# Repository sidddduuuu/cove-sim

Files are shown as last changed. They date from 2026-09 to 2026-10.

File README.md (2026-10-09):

# Cove

Cove is a concept for a wave-powered offshore station that could recharge autonomous underwater vehicles (AUVs) and support repeated inspection missions. This repository contains **screening simulations, concept CAD, and a prototype plan**. It does not yet contain measured full-scale power output or autonomous AUV docking results.

- [Architecture, assumptions, and scaling](ARCHITECTURE_AND_SCALING.md)
- [Business analysis and customer questions](BUSINESS_ANALYSIS.md)
- [Two-week physical MVP plan](HOW_TO_BUILD_THE_MVP.md)
- [Good Bull pitch plan and display model](pitch/GOOD_BULL_2026.md)
- [Generated simulation results](RESULTS.txt)

The current Cove-S concept uses relative motion between a surface hull and submerged reaction body to drive a generator. The printed internal-mass prop in the pitch folder illustrates an earlier idea and is not a working generator or a model of the current architecture.

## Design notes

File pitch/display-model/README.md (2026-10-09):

# Cove pitch display model

This is a **nonfunctional, early internal-mass concept prop** for explaining wave-relative motion. The current Cove-S simulation and CAD instead depict a surface body and submerged reaction body with a power takeoff between them. Do not present this print as a scale model of that architecture or as evidence of electrical generation, watertightness, or autonomous AUV docking.

## Files and printing

- `Cove_shell_section_print_twice.stl`: print **two**; each section is 110 mm across and 85 mm tall, with a front cutaway.
- `Cove_end_cap_print_twice.stl`: print **two**; each cap is 110 mm across and 5 mm thick, with a 6.6 mm center hole.
- `Cove_pitch_model_preview.png`: assembly concept illustration, not a validated engineering drawing.

Suggested first slicer settings: PLA, 0.24–0.28 mm layers, three walls, 10–15% infill, no supports. Lay caps flat and print shell sections upright. Check the slicer preview and fit to your own printer before committing to a long print.

## Assemble

1. Glue the two shell sections end to end, aligning the openings. Glue on the bottom cap.
2. Place a smooth 6 mm rod or dowel about 180 mm long through the cap centers, fixed to the bottom cap.
3. Add a compression spring, a visible stack of M6 fender washers, and a second spring. Choose springs with an inside diameter over 6 mm. Check for roughly 20–40 mm of smooth travel.
4. Add the upper cap after confirming that the washer stack moves freely when the shell is moved vertically.
5. Make a visual AUV and cradle from a marker body, printed shape, pipe section, or foamboard. Mount the cradle below the shell on a rigid stand. It is a **dock mockup**, not a functioning charger.

Photograph the complete display, the cutaway, and a person holding it for scale. A short motion video can be captioned: **“Inertial-motion illustration; electrical output not tested.”**

If printing slips, a clear 100–120 mm plastic container, cardboard caps, and the same rod/washer/spring arrangement can serve as a fallback. The motion and honest labeling matter more than the finish.

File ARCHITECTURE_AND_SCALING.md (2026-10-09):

# Cove architecture and scaling: MVP → Cove S → Cove M → Cove L

This is the technical entry point for a new reader. See also [Business analysis](BUSINESS_ANALYSIS.md), [How to build the MVP](HOW_TO_BUILD_THE_MVP.md), and the [Good Bull pitch plan](pitch/GOOD_BULL_2026.md).

## Read this first

**Cove is an ocean-robot service-platform concept.** Its first proposed product, **Cove S**, is a mobile, wave-powered station that stores energy and recharges small autonomous underwater vehicles (AUVs) at a submerged dock. Its wave-driven propulsion is intended to reposition the station between service areas. The intended small-AUV battery class is roughly **1.5–5 kWh**.

The repository contains energy-balanced *screening* simulations, a draft detailed dynamics dashboard, concept CAD, and an at-home MVP build plan. None of these proves that a full-scale station can harvest the assumed power, survive offshore conditions, propel itself at the assumed speed, or dock an AUV unattended. Treat numerical outputs as conditional on assumptions until hardware and site-specific wave data validate them.

**Design-status convention used below:** *observed* = an identified measurement; *derived* = an equation or calculation from stated inputs; *assumed* = an unvalidated model parameter; *target* = desired future performance. Do not turn a target into a performance claim.

## Product architecture

```text
                  SURFACE PLATFORM (~8 m Cove S concept)
        navigation + communications + control + small auxiliary battery
                       wave-excited floats / hull
                                │
             compliant or telescoping connection with PTO
             relative heave → generator → power electronics
                                │ power/data umbilical and load path
                                │ mean depth target: 15–30 m
                                ▼
                   SUBMERGED REACTION BODY
            heave reaction + wave-propulsion hinged foils
             main battery pods + maneuvering thruster
                                │
                    funnel/latch/charging dock
                                ▼
                         visiting AUV
```

The surface body and submerged reaction body move differently in waves. Their **relative heave** must pass through a power-takeoff (PTO) mechanism to generate electricity. A rigid fixed-length beam that prevents relative axial movement cannot simultaneously provide substantial power from this heave-PTO path. The connection architecture must allow travel, carry structural loads, protect the umbilical, and handle end stops and overloads. Taut fixed-length tethers in parallel with the PTO would bypass its travel; a physically coherent safety/load path still needs engineering.

The submerged body is intended to react against wave motion, carry the dock in lower-motion water, and support hinged foils that turn part of the wave-induced motion into forward thrust. An electric thruster is reserved for maneuvering and low-wave contingencies. The **latest packaging concept** places the main battery in submerged pressure pods and only a small auxiliary battery on the surface hull. Some older model text and calculations still assume a surface battery; mass, buoyancy, cable losses, and power routing have not been reconciled. Neither battery should ride on the moving PTO member.

The dock is a vehicle-specific system, not just a funnel: an operational version needs navigation/acoustic or other homing, capture, latch, charging interface, communication/data offload, safe abort/release, and a fault-handling procedure. The MVP deliberately tests only guided passive capture, not autonomous docking or wet charging.

## Energy and mission model

The reduced-order Cove S model lives in `cove-s/cove-s-model.mjs`. It estimates whether an **assumed** wave-power capture and wave-propulsion capability could support station travel, hotel loads, battery reserve, and scheduled AUV charging.

Deep-water wave flux per metre of crest is screened as:

```text
J = ρ g² H² T / (64π)
```

where `H` is significant wave height and `T` is energy period. Electrical output is bounded by generator rating and calculated from wave flux × effective capture width × period response × PTO efficiency × the share remaining after propulsion allocation. The battery ledger integrates:

```text
ΔE = (Pwave − Photel − Pthruster − Pdock) × Δt
```

A charge session starts only if the station battery can finish while protecting its reserve. These equations are useful for consistency and sensitivities, but they do **not** establish a real capture width or propulsion map.

| Cove S screening input | Current default | Evidence status |
|---|---:|---|
| AUV pack / arrival | 3 kWh / 20% charge | Scenario assumption |
| Visits | 1 per day | Scenario assumption |
| Dock | 1.5 kW at 85% efficiency | Design assumption |
| Main battery | 60 kWh, 20% protected reserve | Design assumption; packaging unverified |
| Hotel load | 60 W | Design assumption |
| Generator ceiling | 2 kW | Rated-output target, **not average output** |
| Effective capture width / PTO efficiency | 0.35 m / 68% | Unmeasured assumptions |
| Energy allocated to wave propulsion | 18% | Unmeasured assumption |
| Maximum wave-driven speed | 1.5 knots | Unmeasured target |
| Service window | 6 hours per day | Scenario assumption |

At these defaults, one daily visit needs about **2.82 kWh from the station** to deliver 2.4 kWh to the AUV. With 60 W hotel load, the station needs at least **~178 W average generation** before propulsion and other losses. The 2 kW ceiling says nothing about whether that average is achieved across calm periods or at a customer's site. The model's four deterministic scenarios—design, variable, calm, storm—are screening histories, not annual site records.

### Detailed dashboard status

`cove-s/detailed/physics.mjs` and the four generated views (`whole.html`, `power.html`, `underwater.html`, `surface.html`) form a **draft** two-body heave/load simulation. It uses 2024 NOAA NDBC station 46005 observations stored in `cove-s/detailed/data/observations.json`; the data preparation keeps rows with simultaneous valid wave-height, dominant-period, and wind values. Preset sea states select real observation rows, while some stress cases are synthetic. Current is assumed, not observed. The model uses assumed hydrodynamic coefficients—not measured response functions or a WEC-Sim/BEM solution.

Its current default case warns that estimated travel exceeds an **assumed ±1.5 m PTO limit**; a **40 kN dynamic-force screening threshold** is also a model warning, not a certified structural rating. Do not hide these warnings or interpret model power outside the assumed envelope as deliverable. The detailed dashboard is not integrated into the root build/navigation; its model explanation is consolidated here.

The most important unfinished engineering tasks are: choose and model a buildable connection/load path; establish static preload and buoyancy equilibrium; replace guessed heave and damping coefficients; couple drag and surge to actual motion; reconcile battery pods, masses, and power routing; model stroke stops and storm survival beyond linear extrapolation; use sufficiently long and varied sea records; and carry uncertainty/validity metadata through the UI. A rigid-lock comparison should tend toward zero relative heave and zero heave-PTO output.

## The physical MVP and the scale-up path

These are **development stages**, not four finalized product specifications. Only Cove S has a concept envelope. Cove M and L should be sized *after* customer missions and measured S performance, not by multiplying CAD dimensions.

| Stage | Purpose | Hardware scope | Evidence needed before advancing |
|---|---|---|---|
| **Home MVP** | Show motion-to-electric conversion and guided dock geometry in 14 days | 0.4–0.6 m float, adjustable submerged plate, small line-driven generator, dry-side resistor/logger, 3D-printed funnel and passive vehicle | Repeated measured watts/Wh above baseline, logged stroke, retrievable buoyant rig, and reported guided-capture rate. See [build guide](HOW_TO_BUILD_THE_MVP.md). |
| **Cove S prototype** | Serve one specified small powered AUV at a chosen coastal/offshore test site | Engineered two-body WEC, protected storage, vehicle-specific submerged dock, navigation/control, supervised operations | Measured net wave-to-battery power matrix, repeated real-vehicle docking/charging, survival and maintenance evidence, site-specific energy ledger, permitting path. |
| **Cove S product** | Repeat the same job for multiple customers or sites | Design-for-manufacture station with documented interface, deployment/recovery procedure, remote operations and spares | Reliable unattended service interval, economics versus vessel/fixed dock, repeatable builds, support and liability model. |
| **Cove M (provisional)** | Support more frequent visits, larger AUV energy demand, or multiple compatible vehicles | Potentially larger converter, storage, and/or multi-vehicle dock; architecture selected from requirements | A named customer mission that S cannot meet; measured power/sea-state scaling; new structural, stability, and mooring/propulsion validation. |
| **Cove L (provisional)** | Support high-duty or multi-vehicle campaigns across a larger operating area | May require a different hull, WEC, dock, energy source mix, or service model—not merely enlarged S parts | Contract-level demand and economics plus full naval-architecture, safety, environmental, certification, and fleet-operations evidence. |

**Scale the validated service, not just the structure.** At each step, specify target vehicle(s), daily energy delivered, peak dock power, operating region and wave climate, station-keeping/mobility needs, recharge frequency, acceptable downtime, deployment/retrieval method, and permitted modification of the AUV. Size the WEC and buffer from the **worst credible operating window**, then check fatigue, stability, sealing, loads, biofouling, collision risk, and maintenance access. More visits and larger AUVs may require a different architecture altogether.

### Validation roadmap

1. **MVP evidence:** Measure motor/generator characteristics, output to a known load, PTO stroke, and guided dock capture. Log raw data and uncertainty. Do not claim AUV charging.
2. **Mechanism validation:** Bench/dynamometer-test PTO force–velocity behavior and losses. Wave-tank or controlled-water tests must measure both electrical power and relative motion across multiple wave states.
3. **Site and system model:** Replace effective capture width and speed assumptions with measured power and propulsion maps. Replay annual wave histories for an actual customer region. Balance generation, hotel load, propulsion, charging, and reserve.
4. **Vehicle-specific dock:** Choose one AUV interface. Test approach, capture, latch, power transfer, data transfer, abort, and release repeatedly under increasing motion/current.
5. **Offshore prototype:** Assess structural and fatigue loads, watertightness, corrosion, biofouling, stability, navigation safety, communications, environmental effects, and recovery. Obtain location-specific approvals before deployment.
6. **Commercial S, then M/L:** Validate total customer economics and reliability. Move up-market only when a real mission requires it and the smaller system's measured limits are known.

For the detailed dynamics model, essential invariant tests are: zero waves yield zero wave-generated power; zero relative velocity or zero PTO damping yields zero damper power; rigid lock suppresses the heave-PTO path; energy ledgers close; drag direction reverses with relative flow; and invalid stroke/load cases are flagged rather than ranked as feasible. Check source timestamps/units and missing values when preparing observational data.

## Repository map and how to run it

| Area | Contents | Status |
|---|---|---|
| `cove-s/cove-s-model.mjs` + `check-cove-s.mjs` | Deterministic mission/energy model and tests | Screening model; wired into root build |
| `cove-s/cove-s-simulation.template.html` → `cove-s-simulation.html` | Offline interactive mission page | Generated from source |
| `cove-s/detailed/` | `physics.mjs`, `ui.js`, four-view dashboard template/build/tests, NOAA preparation and observations | Draft; separate build |
| `cove-s/cad/` | CadQuery master, STEP/STL exports, renders | Packaging concept only |
| `strip/`, `sheet/`, `product/` | Earlier piezoelectric screening concepts | Retained as rejected/learning models |
| `tube/` | Earlier moving-magnet pipe screening concept | Retained as rejected/learning model |
| `node/` | Earlier sealed-pendulum node concept | Retained as a separate exploration |
| `build.mjs` / `run.mjs` | Offline page builder / parameter sweeps | Outputs generated HTML / `RESULTS.txt` |

Earlier piezoelectric options produced only microwatt-scale outputs in the model against a multi-kWh AUV pack. The upright moving-magnet pipe was mistuned to a typical wave period; the horizontal version trades tuning for friction and becomes very large for one charge/day. These are **model outcomes**, not physical measurements. The full parameter sweeps are generated in `RESULTS.txt`; the old concepts remain in code so assumptions can be inspected or retested.

Run from the repository root with Node 18+; the simulation scripts have no package-install step:

```bash
node strip/check.mjs
node sheet/check-sheet.mjs
node product/check-full.mjs
node tube/check-tube.mjs
node node/check-node.mjs
node cove-s/check-cove-s.mjs
node cove-s/detailed/check.mjs
node build.mjs
node cove-s/detailed/build.mjs
node run.mjs                  # regenerate RESULTS.txt
```

`strip/simulation.html` is hand-authored; the other root simulation pages are built from `*.template.html` plus model source. Do not hand-edit generated HTML. Change the corresponding model/template and rebuild. The model modules are deterministic and self-contained because builders inline them; Cove S's energy-residual and reserve checks should keep passing after changes. The detailed model uses SI internally; the mission model reports W, Wh, hours, metres, seconds, and knots.

To regenerate the observational dataset, use `python3 cove-s/detailed/prepare-data.py`. An optional browser smoke test is `python cove-s/detailed/browser-check.py` with Playwright and a suitable Chrome installation; it does not replace physics validation.

### Concept CAD and its limits

The editable CAD master is `cove-s/cad/cove_s_cad.py` (CadQuery, millimetres). It includes an approximately 8 m surface hull, PTO/generator housing, reaction body, foil pairs, maneuvering thruster, submerged dock, battery/power-electronics packaging, and a representative 2.7 m AUV. Exports under `cove-s/cad/exports/` include compact, operating-depth, and exploded STEP assemblies; component STEP/STL files are under `exports/parts/`, with previews in `renders/`.

```bash
uv run --with cadquery python cove-s/cad/cove_s_cad.py --export
```

Change the `Design` data class in the source to revise the envelope. The CAD is **not fabrication-ready**: it does not establish hull stability, PTO/tether loads, fatigue life, foil hydrodynamics, docking capture, pressure-housing integrity, mass/buoyancy balance, or maintenance access. A small FDM printer is most useful for MVP brackets, spool, guides, and a modular docking funnel—not pressure housings or primary offshore structural parts.

## Team ownership for the three-person MVP

- **Mechatronics lead:** PTO, float/plate structure, fasteners, spring/stops, electrical protection, and physical repairs.
- **Oceanography lead:** test-water setup, wave/sea-state characterization, ballast and depth choices, site representativeness, and interpretation of motion.
- **CS lead:** calibrated time-series logging, energy calculations (`P = V × I`, integrated Wh), test metadata, capture-trial records, plots, and reproducibility. Later this role expands to vehicle homing, docking control, charge-state logic, faults, telemetry, and fleet operations.

All three own safety and interpretation. The fastest convincing day-14 result is a **measured, repeatable experiment with honest limits**, not a claim that the eventual offshore station is already feasible.

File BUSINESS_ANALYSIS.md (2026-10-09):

# Cove business analysis

**Research snapshot:** September 29, 2026. **Geography:** United States and Europe. **Product in scope:** The mobile, wave-powered small-AUV charging station described in the [architecture and scaling guide](ARCHITECTURE_AND_SCALING.md).
**Evidence standard:** Public sources establish activities and stated capabilities, not purchasing intent. Vendor claims are identified as such. Inferences and unanswered questions are labeled.

## Executive assessment

Cove-S addresses a real operational constraint: battery-powered autonomous underwater vehicles (AUVs) may require a vessel to recover, recharge, and redeploy them. Offshore recharge could extend useful mission time and reduce some recovery effort. The [U.S. Department of Energy](https://www.energy.gov/sites/prod/files/2019/03/f61/73355.pdf) identifies AUV recharging as a potential marine-energy application, and [NOAA research](https://repository.library.noaa.gov/view/noaa/67166) identifies endurance and vessel-supported servicing as barriers to shipless survey.

The market is **not empty**. A [University of Washington field demonstration](https://www.nature.com/articles/s41598-026-55823-z) combined a wave-energy converter and submerged dock, reporting six successful docking attempts. Commercial vendors offer resident docks, and others are developing moving underwater docks and offshore charging platforms. Cove must therefore win on a particular customer mission, not on the novelty of wave-powered recharge alone.

**Working conclusion:** A focused paid pilot or integration business is plausible. Public evidence does not yet establish a large repeatable market for Cove-S. The major unknowns are customer economics, vehicle compatibility, actual net energy output, docking reliability, and the value of mobility.

## Customer job and product hypothesis

The customer would not buy wave energy for its own sake. The proposed job is to **keep a powered AUV collecting data or inspecting assets without bringing it back for every recharge**. Potential benefits include fewer recoveries, more continuous observations, and a charging location that can move between mission areas. These are hypotheses to test, not measured benefits.

The present [Cove-S architecture](ARCHITECTURE_AND_SCALING.md) proposes an approximately 8 m surface platform, wave-energy conversion, wave-driven propulsion, and a dock 15–30 m below the surface for AUVs with roughly 1.5–5 kWh battery packs. Its CAD and simulations are concept-stage screening tools, not proof of offshore performance.

### Energy-budget gate

The default [mission model](ARCHITECTURE_AND_SCALING.md) assumes one 3 kWh AUV visit per day, arrival at 20% state of charge, 85% dock efficiency, and a 60 W station hotel load:

| Quantity | Calculation | Result |
|---|---:|---:|
| Energy delivered to AUV | 3 kWh × 80% | 2.40 kWh/visit |
| Energy drawn from station | 2.40 kWh ÷ 85% | 2.82 kWh/day |
| Station hotel load | 60 W × 24 h | 1.44 kWh/day |
| **Minimum sustained generation** | (2.82 + 1.44) kWh ÷ 24 h | **~178 W average** |

That average excludes propulsion, communications peaks, storage losses, and calm-weather reserve recovery. The modeled **2 kW generator rating is a maximum, not evidence of 178 W sustained average generation**. Capture width, power-takeoff efficiency, and propulsion performance remain assumptions. For context, the published [UW TigerRAY demonstration](https://www.nature.com/articles/s41598-026-55823-z) was designed for 100 W in its target conditions; it is not an apples-to-apples performance comparison with Cove. Its testing illustrates the importance of measured wave-to-wire output and power-electronics losses.

The team should select a real customer vehicle and operating region before asserting a charge-per-day capability. Historical sea states can be screened with [NOAA NDBC archives](https://www.ndbc.noaa.gov/historical_data.shtml) in the United States and [Copernicus Marine wave reanalysis](https://data.marine.copernicus.eu/product/GLOBAL_MULTIYEAR_WAV_001_032/description?product_id=-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) for European regions.

## Customer segments

| Segment | Potential reason to care | Main qualification question | Priority |
|---|---|---|---|
| Powered-AUV research teams | Longer sampling campaigns and fewer vehicle recoveries | Does recharge solve an actual mission bottleneck, or are payload, data, and vessel logistics more limiting? | First interviews and pilots |
| Commercial survey and offshore-inspection operators | Vessel time and continuous inspection coverage have economic value | Can Cove beat an existing vessel, resident dock, or uncrewed surface vessel on total operating cost and reliability? | Early economic validation |
| AUV makers and dock integrators | Possible power-and-docking platform partnership | Will they support a reusable charging interface rather than a one-off custom integration? | Partnership interviews |
| Defense and government operators | Persistent, potentially relocatable underwater operations | What mission and sponsor can be discussed and tested openly? | Later, unless a direct sponsor exists |

These are **prospect categories, not validated buyers**. [WHOI](https://www.whoi.edu/what-we-do/explore/underwater-vehicles/auvs/remus/) develops and operates REMUS AUVs, the [UK National Oceanography Centre](https://www.noc.ac.uk/our-work/marine-technology) operates an underwater-robot fleet, and [Oceaneering](https://www.oceaneering.com/rov-services/rov-systems/freedom-autonomous-underwater-vehicle/) markets a resident-capable AUV. None of those facts establishes demand for Cove.

**Likely initial fit — inference:** a powered AUV carrying energy-intensive sensors or repeating short missions. Extremely low-power gliders may be a weaker first segment because existing models can operate for long periods. [Teledyne](https://www.teledynemarine.com/products/product-line/autonomous-underwater-glider) describes long-endurance Slocum gliders; [NOC](https://www.noc.ac.uk/news/european-research-institute-acquire-noc-autonomous-underwater-vehicles) describes multi-week to multi-month Autosub Long Range missions.

## Competitive and substitute landscape

| Alternative | Evidence | What Cove must demonstrate |
|---|---|---|
| Recover and recharge from a vessel | [NOAA](https://repository.library.noaa.gov/view/noaa/67166) identifies endurance, recovery, and servicing as obstacles to shipless survey. | Sufficient avoided recovery work or added mission output to justify Cove's full cost. |
| More onboard energy or long-endurance vehicles | [NOC](https://www.noc.ac.uk/news/european-research-institute-acquire-noc-autonomous-underwater-vehicles) and [Teledyne](https://www.teledynemarine.com/products/product-line/autonomous-underwater-glider) show long-endurance alternatives. | A mission that remains energy-limited despite these options. |
| Fixed or resident subsea docks | [Saab Sabertooth](https://www.saab.com/products/sabertooth) and [Oceaneering Liberty](https://www.oceaneering.com/rov-services/rov-systems/liberty-resident-system/) offer subsea residence and recharge; Liberty has a large onboard battery. | A meaningful benefit from local generation and independent relocation. |
| Wave-powered underwater-dock research | [UW TigerRAY](https://www.nature.com/articles/s41598-026-55823-z) has field results; [DOE-funded Oregon State work](https://stage.energy.gov/cmei/water/funding-selections-marine-energy-university-foundational-rd) pursues related integration. | A distinct customer outcome, stronger performance, or better deployment economics. |
| Moving docks and offshore charging platforms | [Unplugged](https://www.unplugged.no/projects/underwater-refuelling-in-motion) reports a USV-towed submerged dock with 500 W inductive charging. [Ocean Power Technologies](https://investors.oceanpowertechnologies.com/node/17091) has announced progress on offshore charging and docking. | Why Cove's power source, mobility, dock depth, interface, or operating model wins in a named mission. |

Vendor pages establish what suppliers **claim or are developing**; they are not independent proof that all advertised capabilities work in every sea state.

### Potential differentiation to test

> A relocatable, independently powered charging point for small powered AUVs where a fixed dock or support vessel is impractical.

This is a **positioning hypothesis**, not a verified customer requirement. It depends on all three conditions below:

1. The customer needs the charging point to move during a campaign or between nearby missions.
2. Cove has sufficient *net* energy after propulsion, hotel loads, docking losses, and low-wave periods.
3. A compatible AUV can dock and charge reliably without an uneconomic redesign.

If the customer can leave the dock fixed, mobility may add complexity without adding value.

## SWOT analysis

| Strengths | Weaknesses |
|---|---|
| Cove integrates local generation, relocation, and submerged docking in one concept. A small-AUV focus narrows the initial interface problem. | No measured full-scale output, docking success rate, mobility, survivability, or service interval. Current CAD and models are not validated product performance. [Architecture and scaling guide](ARCHITECTURE_AND_SCALING.md) |
| The proposed customer outcome—less recovery and more useful mission time—is testable. | Energy, navigation, docking, and unattended reliability must all work together. Vehicle-specific integration may make early sales custom projects. |

| Opportunities | Threats |
|---|---|
| AUV users seek less vessel-dependent operations; relevant operators exist in research and inspection. [NOAA](https://repository.library.noaa.gov/view/noaa/67166), [Oceaneering](https://www.oceaneering.com/rov-services/rov-systems/freedom-autonomous-underwater-vehicle/) | Established vendors and funded researchers are already pursuing subsea docks, wave recharge, and moving docks. [UW](https://www.nature.com/articles/s41598-026-55823-z), [Unplugged](https://www.unplugged.no/projects/underwater-refuelling-in-motion) |
| A vehicle-maker or operator partnership could provide a real interface and pilot mission. Historical wave datasets support site screening. [NOAA NDBC](https://www.ndbc.noaa.gov/historical_data.shtml), [Copernicus Marine](https://data.marine.copernicus.eu/product/GLOBAL_MULTIYEAR_WAV_001_032/description?product_id=-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) | Better batteries, low-power vehicles, and uncrewed surface-vessel support may be good-enough substitutes. Deployment approvals and liability may lengthen pilots. [Teledyne](https://www.teledynemarine.com/products/product-line/autonomous-underwater-glider), [Fugro](https://www.fugro.com/expertise/case-studies/ensuring-sustainable-offshore-wind-farm-maintenance-hollandse-kust-zuid-inspection), [U.S. agency overview](https://www.boem.gov/renewable-energy/agency-approval), [UK licensing](https://www.gov.uk/guidance/make-a-marine-licence-application) |

## Market size and economics

**No defensible numeric total addressable market was found.** A broad AUV-industry estimate would include many vehicles and buyers for whom Cove is irrelevant. The serviceable market should instead be counted from named fleets that meet all of these filters:

- A compatible powered AUV and repeated remote missions.
- A material endurance or recovery problem that recharge would solve.
- A viable wave climate and deployment location.
- A technically and commercially feasible dock interface.
- An identifiable buyer and procurement path.

Use a bottom-up model:

```text
Potential stations = qualifying operators × relevant missions/operator × stations/mission
Potential annual revenue = stations sold or deployed × price + service/integration revenue
```

For a customer, the break-even question is:

```text
avoided vessel/recovery cost + value of additional mission output
    > Cove purchase or rental + deployment/retrieval + integration
      + maintenance + insurance + operational risk
```

Reliable public figures for Cove-specific pricing, customer vessel-day costs, willingness to pay, and maintenance burden were **not found**. Those inputs require operator interviews and supplier quotes. **Inference:** early revenue is more likely to come from paid pilots and custom integration than standardized station sales; repeatability depends on a reusable vehicle interface and proven unattended operation.

## U.S. and European outreach map

These are **interview targets, not confirmed buyers**. The best initial contact is usually an AUV operations lead, fleet manager, or mission/program manager.

| Priority | Organization | Reason to contact | Main question |
|---|---|---|---|
| 1 | [WHOI Oceanographic Systems Lab, U.S.](https://www.whoi.edu/what-we-do/explore/underwater-vehicles/auvs/remus/) | Develops and operates REMUS AUVs. | Which powered-AUV missions are recovery-limited, and what interface could be piloted? |
| 1 | [NOAA Office of Coast Survey, U.S.](https://nauticalcharts.noaa.gov/learn/uncrewed-systems.html) | Uses AUVs for hydrographic survey. | Would recharge add survey time, or is another constraint dominant? |
| 1 | [National Oceanography Centre MARS, UK](https://www.noc.ac.uk/our-work/marine-technology) | Operates an advanced AUV fleet. | Which missions still need offshore recharge despite long-endurance vehicles? |
| 1 | [Fugro, Netherlands/UK operations](https://www.fugro.com/expertise/case-studies/ensuring-sustainable-offshore-wind-farm-maintenance-hollandse-kust-zuid-inspection) | Performs remote offshore inspection. | Could Cove beat its existing uncrewed-vessel approach on a specific job? |
| 2 | [MBARI LRAUV team, U.S.](https://www.mbari.org/team/lrauv/) | Extensive AUV and charging experience. | What worked or failed, and where is its [existing solar dock](https://www.mbari.org/news/mbari-research-expedition-provides-a-detailed-snapshot-of-life-in-monterey-bay/) insufficient? Treat as an expert interview, not a greenfield sale. |
| 2 | [ARDITI, Portugal](https://www.noc.ac.uk/news/european-research-institute-acquire-noc-autonomous-underwater-vehicles) | Acquiring two NOC AUVs for offshore science. | Is high-power payload operation constrained by recharge? |
| 2 | [GEOMAR, Germany](https://www.geomar.de/st/auv) | Operates research AUVs. | What are recovery frequency, sea-state limits, and vehicle-modification constraints? |
| 2 | [Ocean Infinity, UK](https://oceaninfinity.com/news/ocean-infinity-launches-needlefish-usv-in-kuwait/) | Operates uncrewed maritime systems. | Would an independent charging node fit its fleet architecture? |
| Expert/partner | [UW Applied Physics Laboratory, U.S.](https://www.nature.com/articles/s41598-026-55823-z) | Direct wave-converter/dock field experience. | What technical and operational lessons should Cove incorporate? |
| Expert/partner | [Unplugged, Norway](https://www.unplugged.no/projects/underwater-refuelling-in-motion) | Developing a closely related moving dock. | Are interface standards or partnership opportunities emerging? |

## Unknowns for customer discovery

Do **not** replace these with unsourced market estimates. Request evidence from recent missions, logs, budgets, quotes, and pilot requirements.

| Unknown | Question for the customer | Why it matters |
|---|---|---|
| Mission pain | In the last 12 months, how many missions ended or paused because of energy? | Establishes frequency and severity. |
| Recovery economics | What vessel, crew, and weather-window effort did a recent recharge/redeployment require? | Sets the value ceiling. |
| Vehicle fit | Which exact AUV, battery, charging protocol, geometry, and permitted modifications? | Determines integration feasibility. |
| Energy demand | How many kWh per visit, how often, and how quickly? | Sets generation, battery, and dock requirements. |
| Mobility | Does the dock need to move? How far and how frequently? | Tests Cove's central differentiator. |
| Reliability | What docking-success rate and unattended service interval would be acceptable? | Defines pilot success and risk. |
| Substitutes | Why not more batteries, a fixed dock, or an existing uncrewed surface platform? | Identifies true competition. |
| Buyer and timing | Who owns the budget, and what evidence is needed for a paid pilot? | Distinguishes interest from purchase intent. |
| Commercial model | Purchase, campaign rental, or service contract? At what budget level? | Enables pricing and market sizing. |
| Deployment | Who handles permits, marking, insurance, recovery, and maintenance? | Determines adoption time and total cost. |

For the first conversation, ask about the **last specific mission before presenting Cove**. A documented recovery event and its cost are stronger evidence than a positive reaction to a concept drawing.

## Proposed validation decision

After 15–20 interviews, proceed toward a customer-specific pilot only if the team has:

1. At least **two operators** with a named recurring mission where offshore recharge would measurably improve results.
2. At least **one vehicle/platform partner** willing to specify a real dock and charging interface.
3. A measured prototype energy budget plausibly sufficient for that mission across its site-specific sea-state history—not just a generator peak rating.

These are **proposed go/no-go criteria**, not sourced market statistics. The existence of an endurance problem is supported; demand for Cove-S's particular solution remains to be validated.

## Research limitations and update triggers

- Public product pages often describe vendor plans or self-reported capabilities, not independently verified deployments.
- An organization's AUV ownership is not proof of a current recharge need, budget, or purchasing authority.
- This report is a September 2026 snapshot. Recheck competitor status, permits, and target organizations before making an investment or deployment decision.
- Update this file with interview evidence, named vehicle specifications, supplier quotes, and measured prototype results. Keep observed facts separate from assumptions.

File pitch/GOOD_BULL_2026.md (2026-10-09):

# Cove at Good Bull Pitch — October 12, 2026

**Format:** 8-minute pitch, then 4 minutes of questions (team-provided timing).

**Purpose:** present a testable business and engineering plan, not a validated offshore product.

## The focus

Lead with one proposed customer job: **repeat inspection of offshore infrastructure, starting with a pipeline corridor**. The buyer would pay for timely inspection data. Cove's proposed wave-powered charging station is the means to keep a compatible AUV operating near that job with fewer recovery trips. A paid data/inspection service is the first business-model hypothesis; charging AUVs owned by other operators is a later hypothesis that requires a proven interface and enough spare energy.

This customer, job, and willingness to pay are **not yet validated**. Do not claim a signed customer, measured vessel savings, or a price without evidence. If interviews identify a stronger first use case, change the pitch accordingly.

## Eight-minute run of show

| Time | Slide / prop | Main point |
|---|---|---|
| 0:00–0:50 | Problem | Repeated AUV recovery and redeployment can interrupt offshore inspection work. Establish this as the customer problem to investigate. |
| 0:50–1:40 | First buyer and mission | Name the proposed pipeline-inspection operator, recurring mission, and value of more frequent data. Avoid a broad claim about all AUVs. |
| 1:40–3:00 | Cove system | Show a surface energy harvester, storage, submerged dock, and one compatible AUV. Describe the mission loop: inspect, dock, recharge, upload, relaunch. |
| 3:00–4:00 | Physical display | Show the scale mockup and explain exactly what it demonstrates. Refer to the [display-model guide](display-model/README.md). |
| 4:00–5:00 | Business model | First, sell a recurring inspection/data service with Cove-operated AUVs; later, consider third-party docking once charging compatibility and capacity are measured. |
| 5:00–6:20 | Evidence and unknowns | Distinguish existing screening calculations and CAD from measured generation, autonomous docking, and offshore reliability. State the next tests. |
| 6:20–7:20 | Milestones and ask | Explain how prize funds would support an instrumented power-takeoff test, guided docking test, and customer interviews. Use an actual budget when available. |
| 7:20–8:00 | Buffer and close | Repeat the intended customer outcome and the immediate validation milestone. |

## Numeric claim discipline

The current Cove-S model is a **screening scenario**. For its assumed 3 kWh AUV arriving at 20% charge, 85% dock efficiency, and 60 W station hotel load, one visit per day needs about **2.82 kWh/day from the station for charging** plus **1.44 kWh/day for hotel loads**: about **178 W sustained average generation** before propulsion and other losses. This is a *requirement derived from assumptions*, not measured Cove output. The model's 2 kW generator ceiling is a target/rating cap, not 2 kW continuous generation.

Do not promise hundreds of missions per day, universal AUV compatibility, or a specific reduction in vessel cost. Count a "mission" only after defining its duration, battery energy, and recharge need. Energy, dock throughput, and maintenance all constrain daily mission count.

## Four-minute Q&A preparation

| Question | Short answer |
|---|---|
| How much power have you generated? | Current numbers are assumption-based models. The next test will log voltage, current, load, motion, and watt-hours over repeatable runs. |
| Why would an operator pay? | The hypothesis is that more frequent inspection data and fewer recovery operations have value. Operator interviews and a mission-specific pilot must establish the economics. |
| Can any AUV dock? | No. The first pilot needs one chosen vehicle, charging protocol, homing method, and mechanical interface. |
| Why waves instead of solar or a larger battery? | Compare a site-specific power mix. Wave energy is a candidate; actual sea-state history and net energy measurements must justify it. |
| Is this working hardware? | The pitch prop is a display mockup. It demonstrates layout or relative motion only; it does not prove wave-to-wire power, autonomous docking, or offshore survival. |

## By pitch day

1. Freeze a seven-slide deck and label every number **measured**, **derived from assumptions**, or **target**.
2. Assemble and photograph the physical display. Use one wide view, one mechanism close-up, and one scale view with a person.
3. If any electrical test succeeds, report the raw load, measurement interval, watts, and watt-hours. If it does not, show the motion/layout only.
4. Rehearse to 7:20, leaving 40 seconds of margin, then practice the five Q&A answers above.

The existing Cove-S model and concept CAD are in [`cove-s/`](../cove-s/). The display-model package below is an **earlier internal-mass illustration** and does **not** implement the current two-body Cove-S power-takeoff architecture. If the deck shows the current architecture, use the repository's Cove-S CAD renders as the primary system visual and introduce this prop only as an early motion concept.

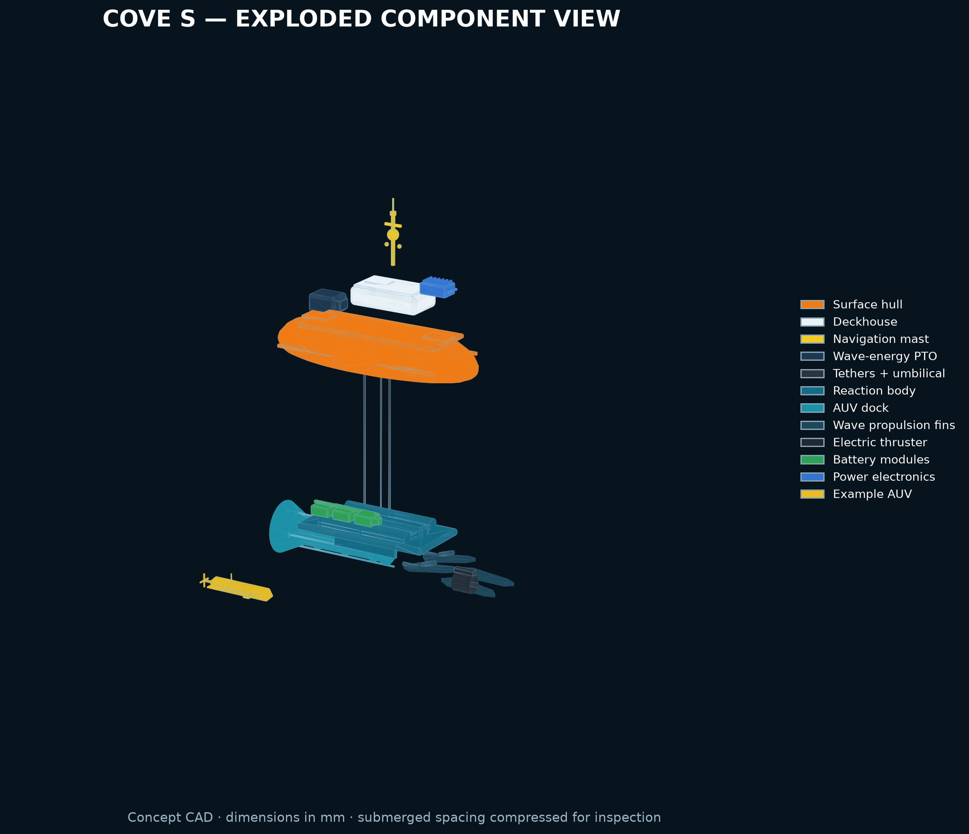
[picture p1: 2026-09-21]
cove-s/cad/renders/cove-s-exploded.png

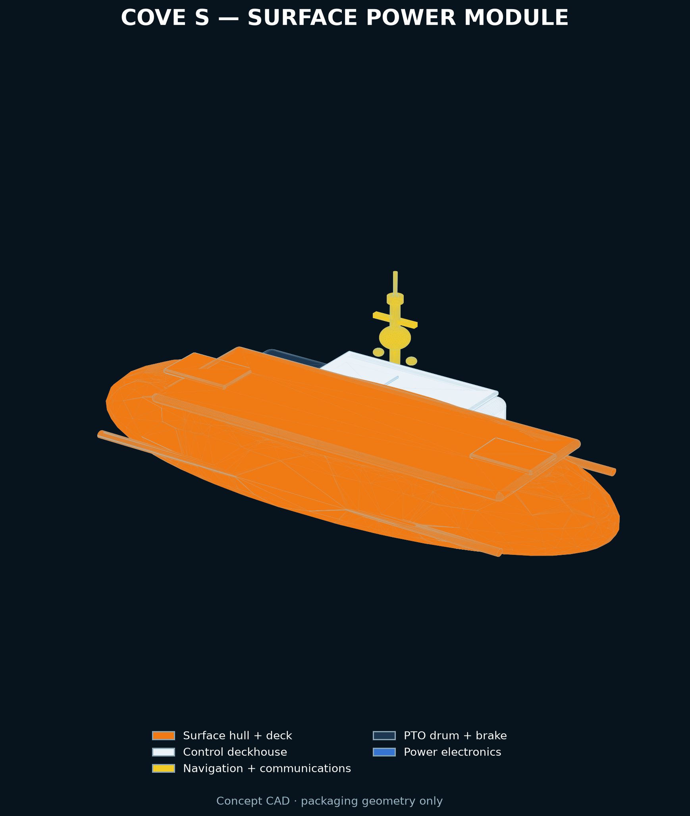
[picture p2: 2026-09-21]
cove-s/cad/renders/cove-s-surface-module.png

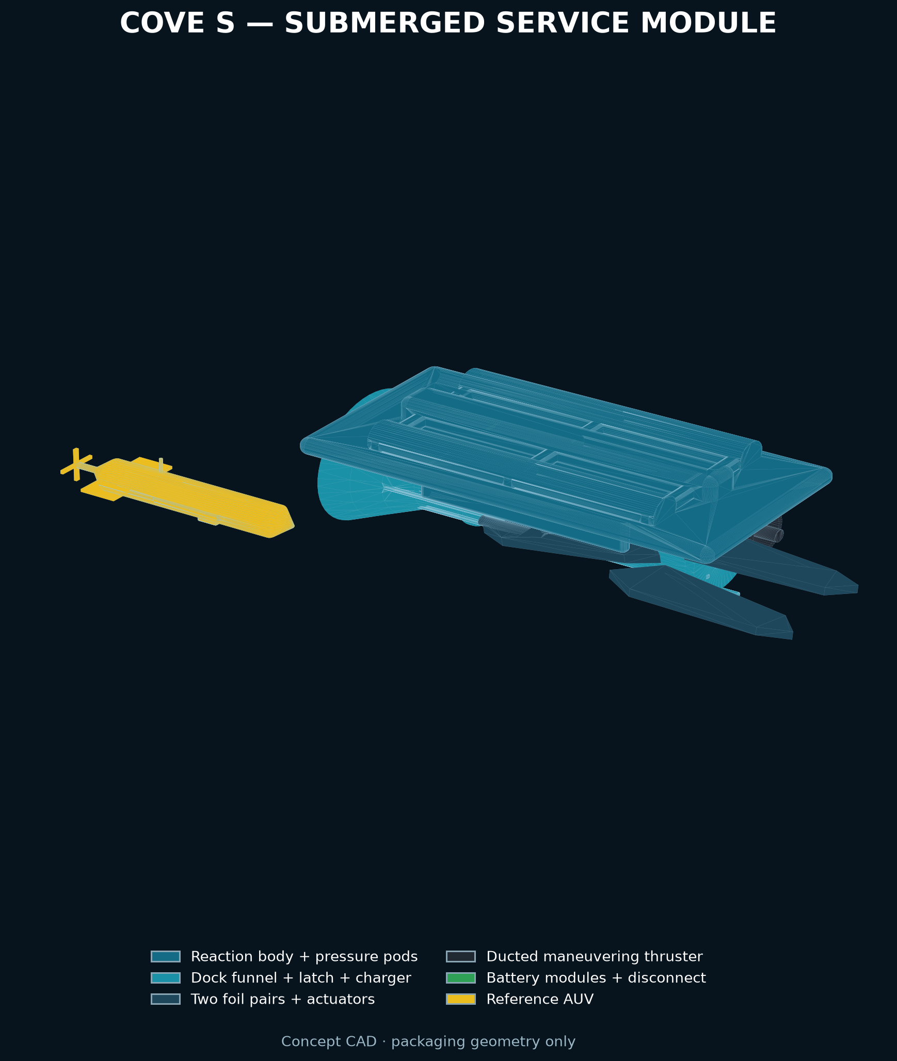
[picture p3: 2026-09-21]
cove-s/cad/renders/cove-s-submerged-module.png

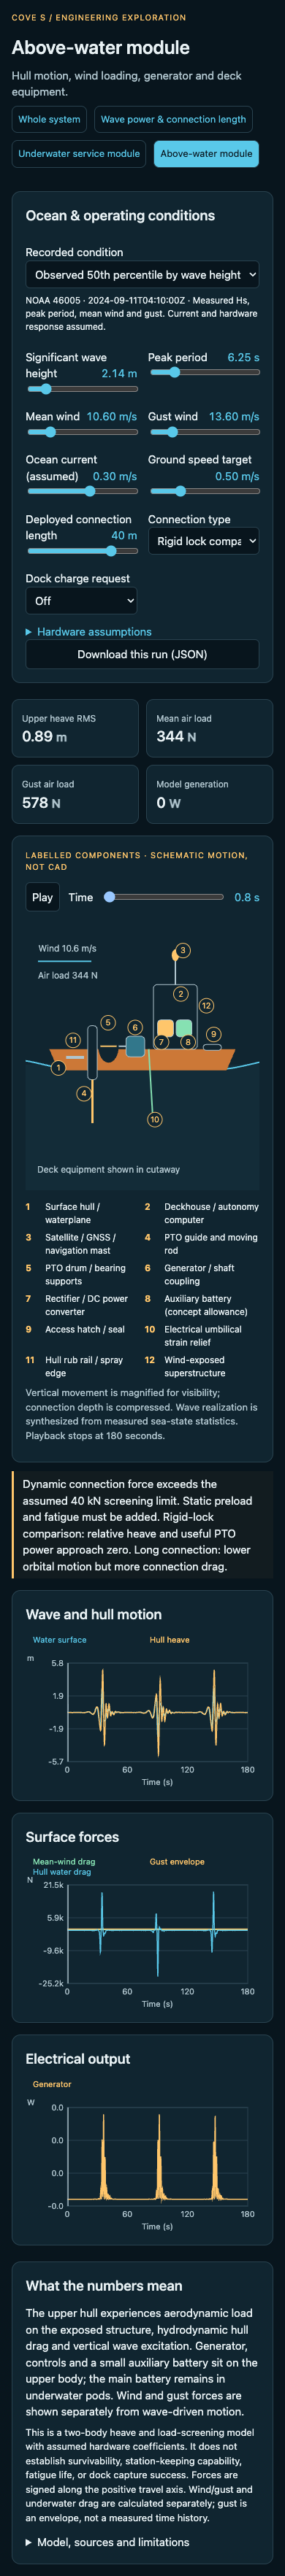
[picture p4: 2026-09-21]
cove-s/detailed/previews/surface-mobile.png

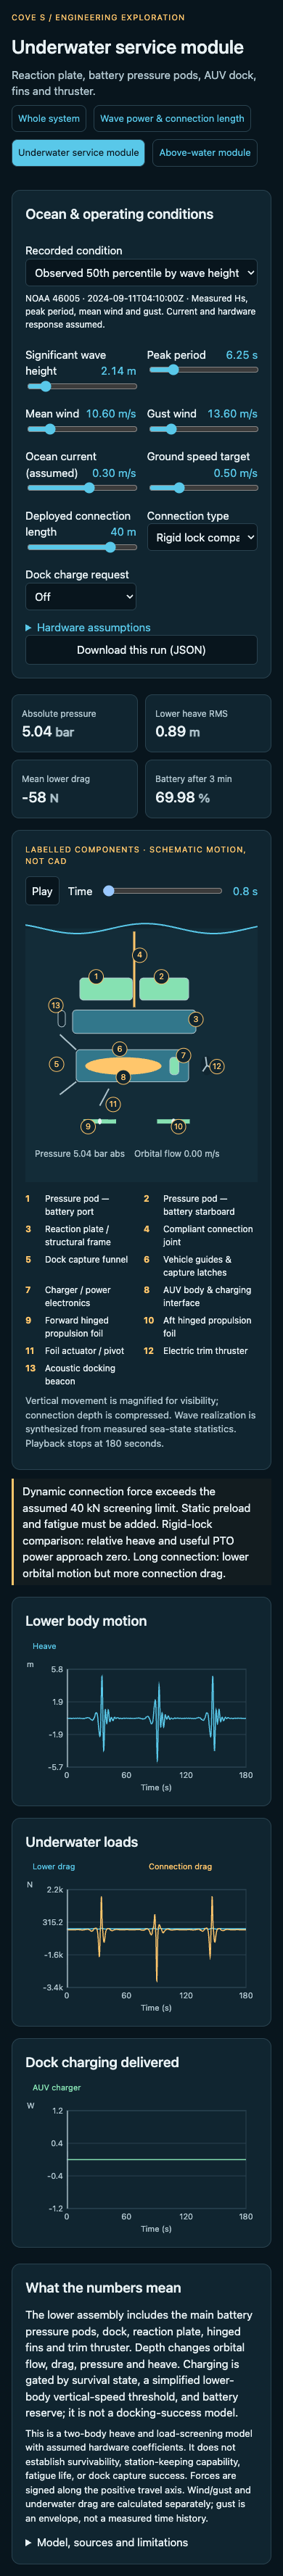
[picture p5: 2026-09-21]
cove-s/detailed/previews/underwater-mobile.png

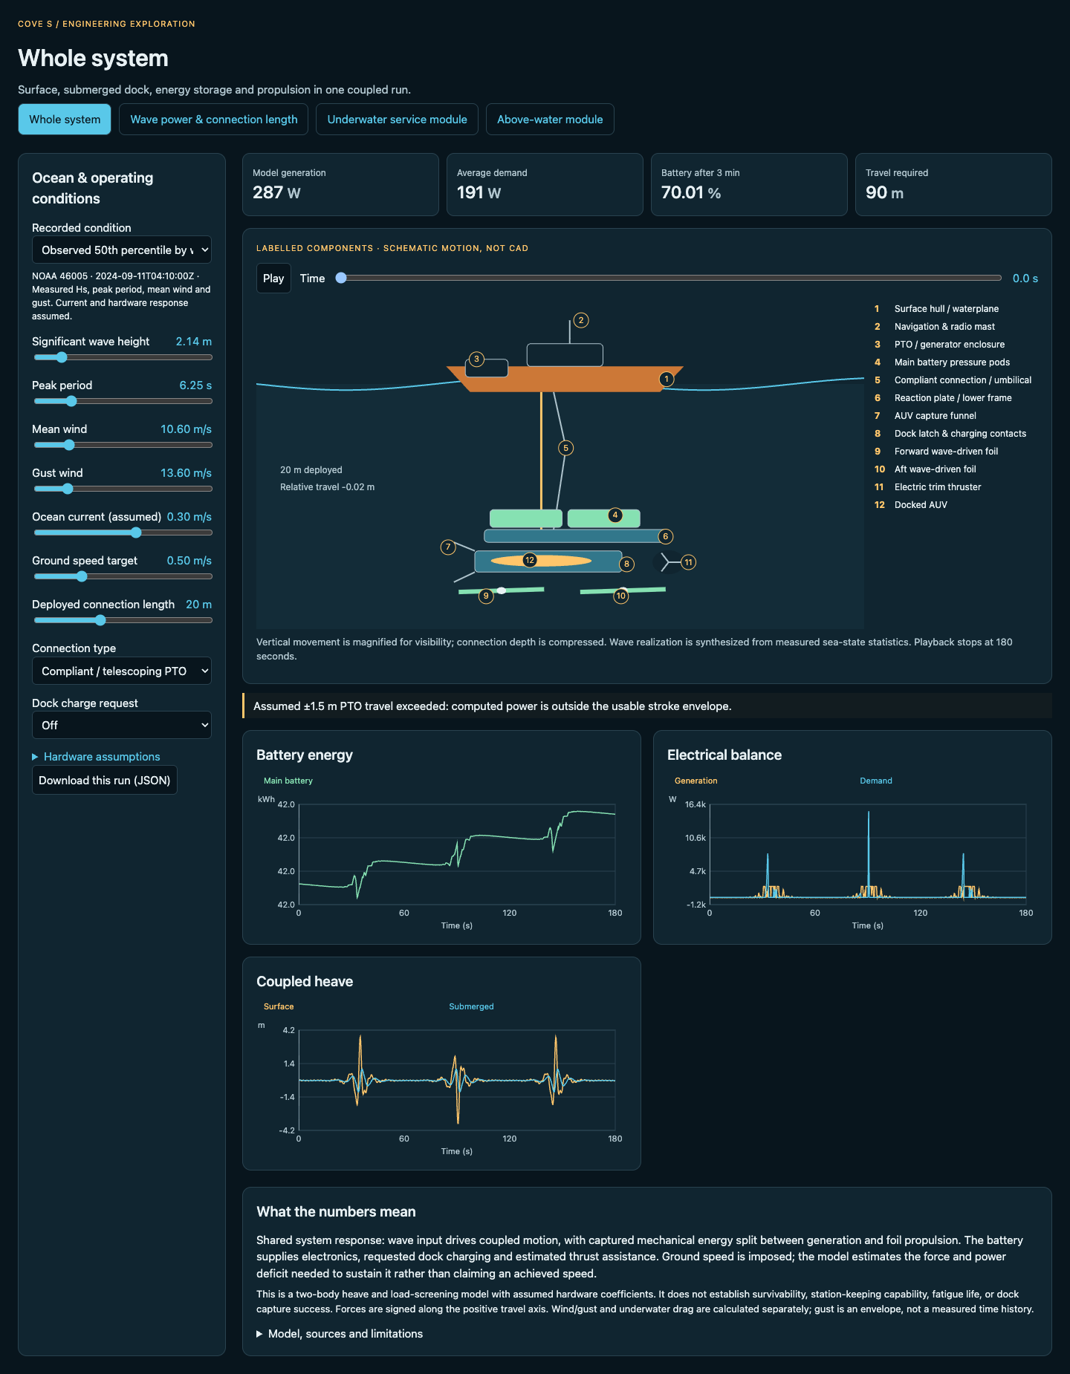
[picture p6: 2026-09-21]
cove-s/detailed/previews/whole.png

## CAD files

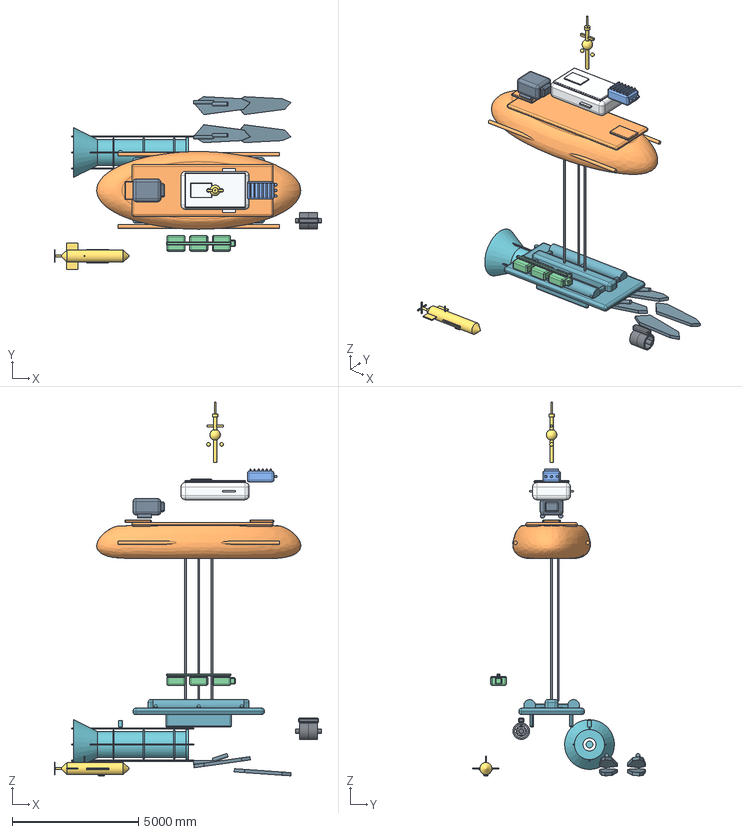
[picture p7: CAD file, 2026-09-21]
cove-s/cad/exports/cove-s-exploded-assembly.step
10587.5 x 6835.0 x 14805.0 mm
surface_hull
deckhouse
mast
pto
tethers
reaction_body
dock
foils
thruster
battery
electronics
auv

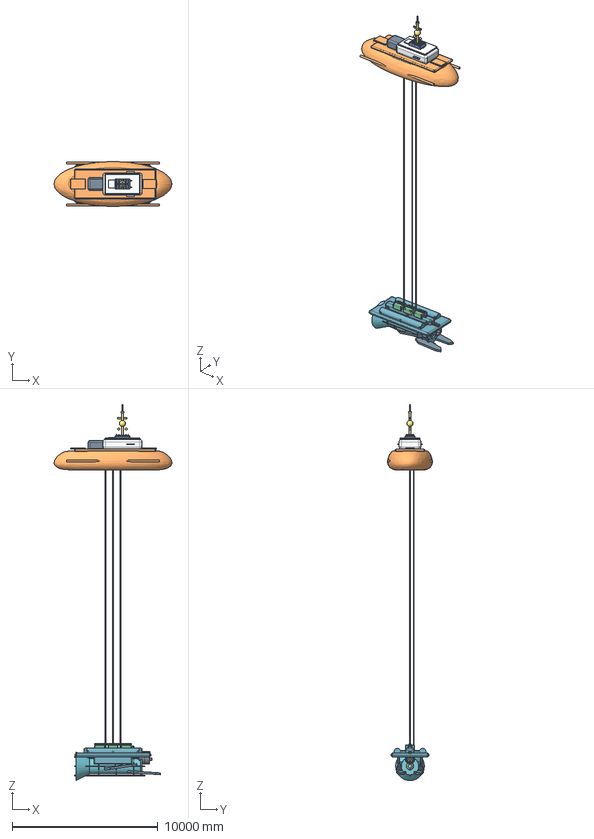
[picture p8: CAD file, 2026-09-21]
cove-s/cad/exports/cove-s-operating-depth-assembly.step
8083.7 x 3078.1 x 25793.1 mm
surface_hull
deckhouse
mast
pto
tethers
reaction_body
dock
foils
thruster
battery
electronics
auv

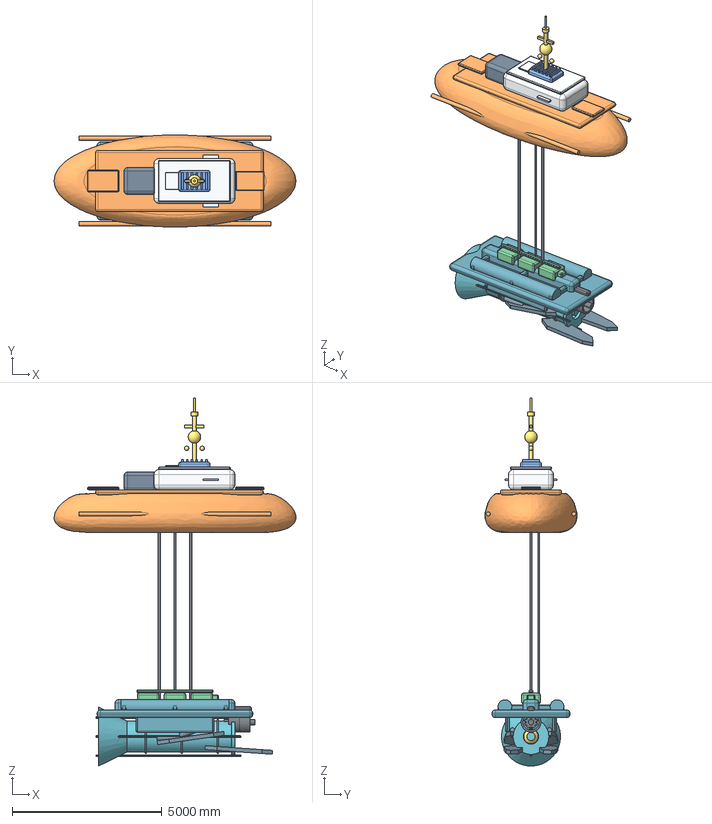
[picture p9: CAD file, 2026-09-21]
cove-s/cad/exports/cove-s-compact-assembly.step
8083.8 x 3078.1 x 12293.1 mm
surface_hull
deckhouse
mast
pto
tethers
reaction_body
dock
foils
thruster
battery
electronics
auv

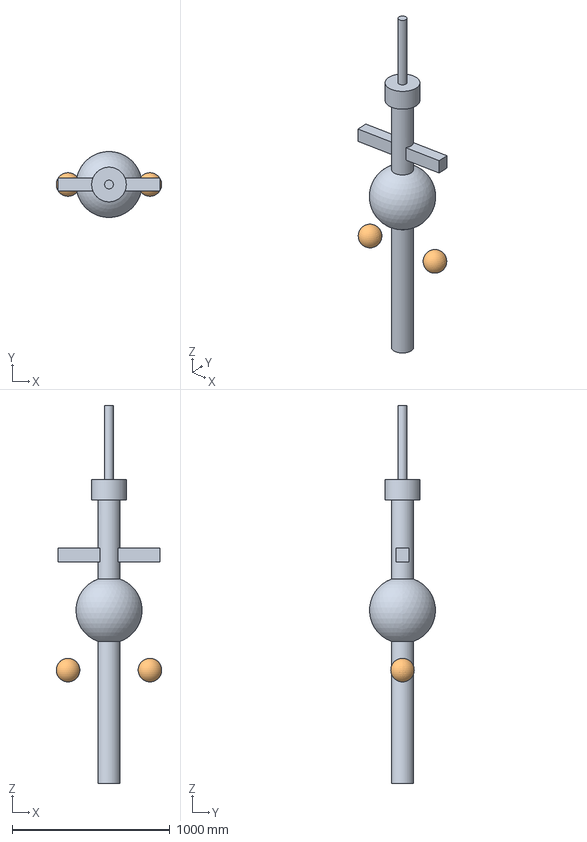
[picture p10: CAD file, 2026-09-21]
cove-s/cad/exports/parts/mast.step
669.7 x 418.6 x 2400.0 mm

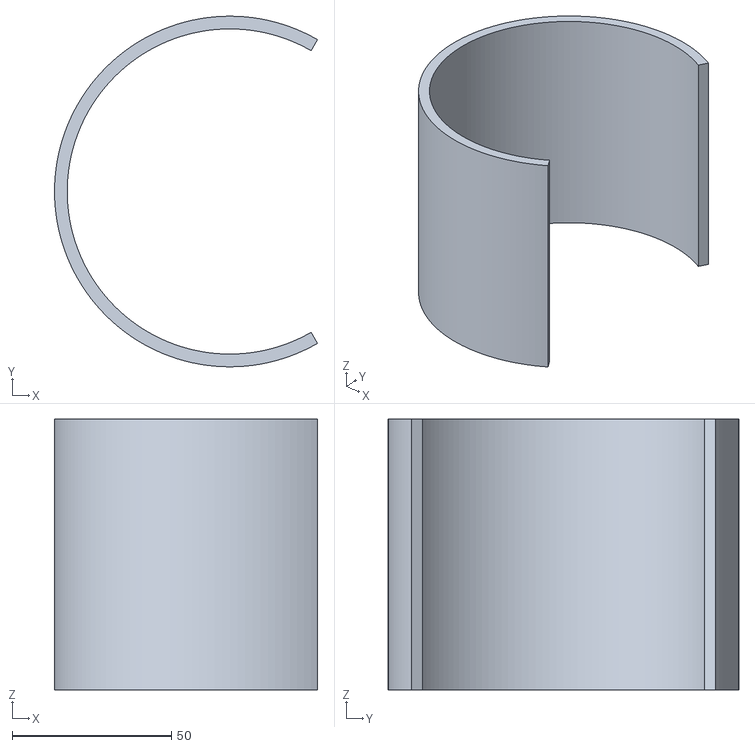
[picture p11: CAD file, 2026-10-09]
pitch/display-model/Cove_shell_section_print_twice.stl
82.5 x 110.0 x 85.0

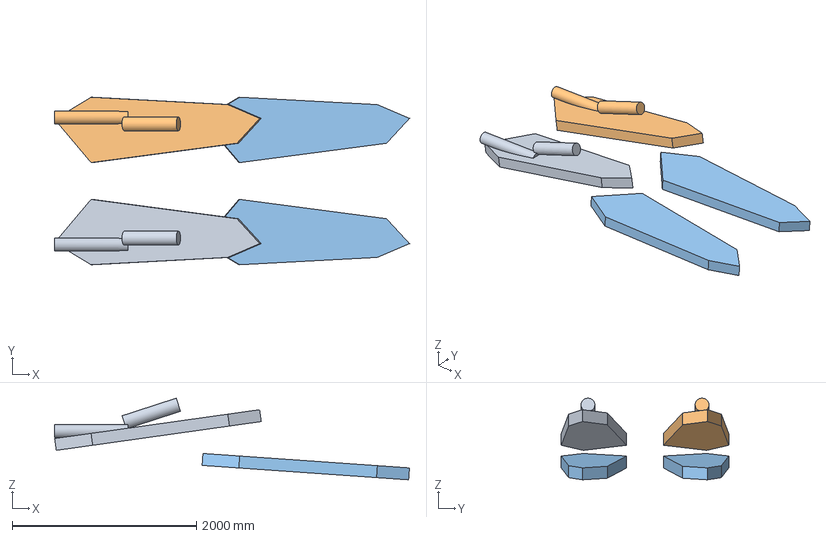
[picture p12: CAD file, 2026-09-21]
cove-s/cad/exports/parts/foils.step
3857.2 x 1820.0 x 887.6 mm

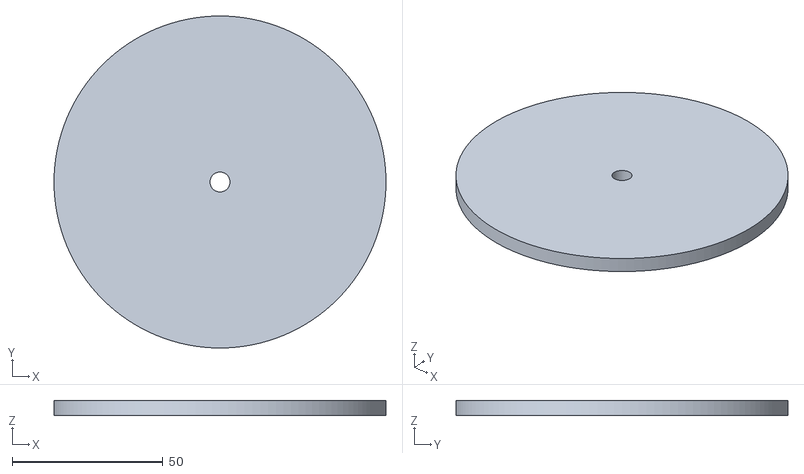
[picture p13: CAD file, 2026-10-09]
pitch/display-model/Cove_end_cap_print_twice.stl
110.0 x 110.0 x 5.00

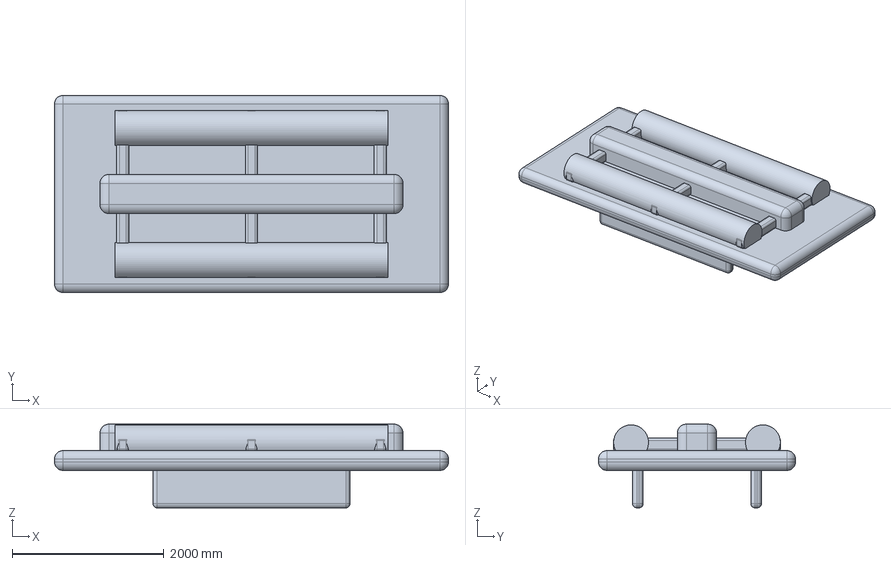
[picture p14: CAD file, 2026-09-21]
cove-s/cad/exports/parts/reaction_body.step
5200.0 x 2600.0 x 1105.0 mm

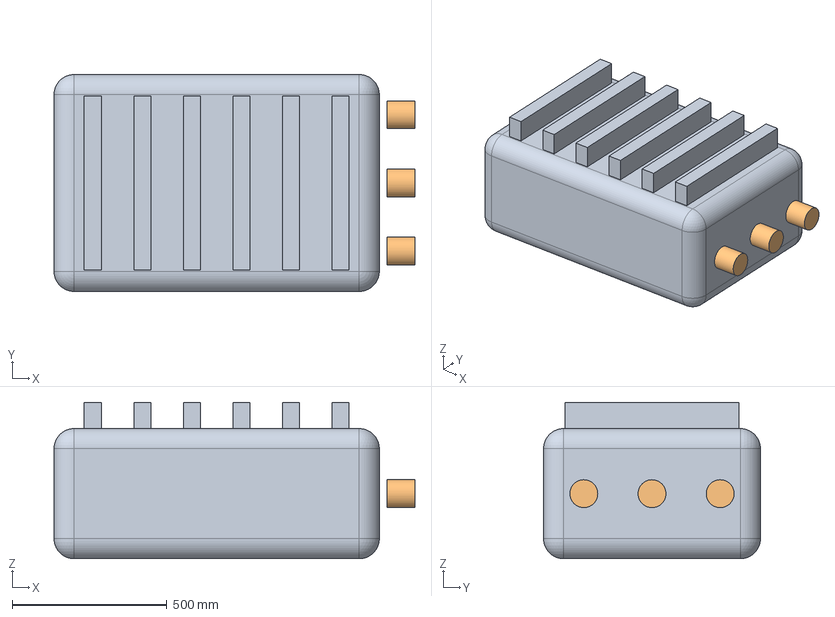
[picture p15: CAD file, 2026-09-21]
cove-s/cad/exports/parts/electronics.step
1165.0 x 700.0 x 505.0 mm

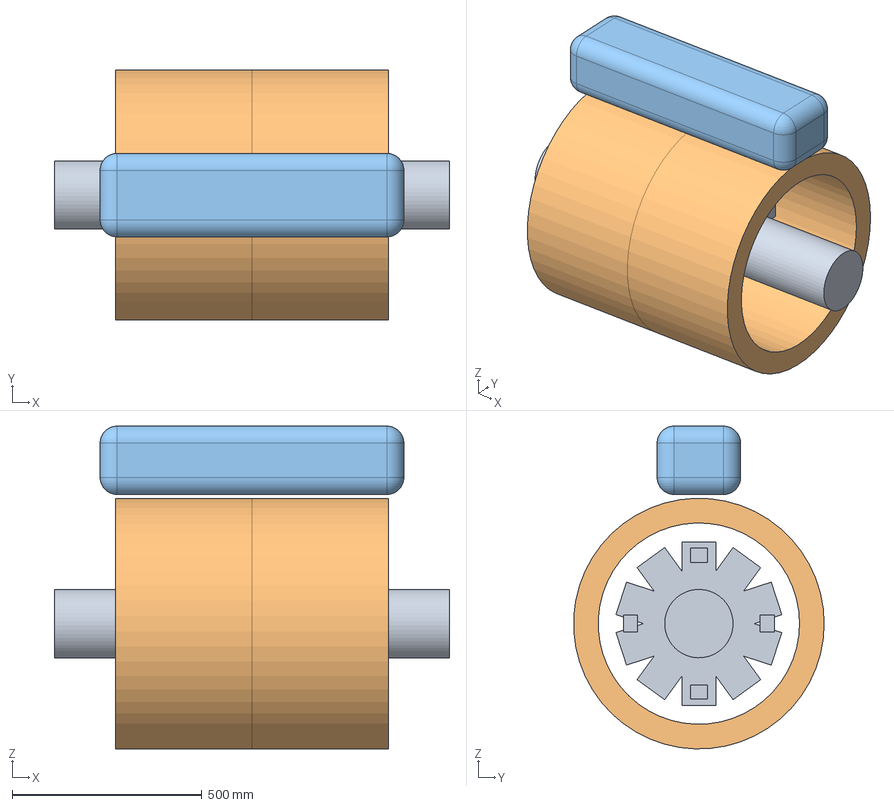
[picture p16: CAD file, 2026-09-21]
cove-s/cad/exports/parts/thruster.step
1040.0 x 659.4 x 849.8 mm

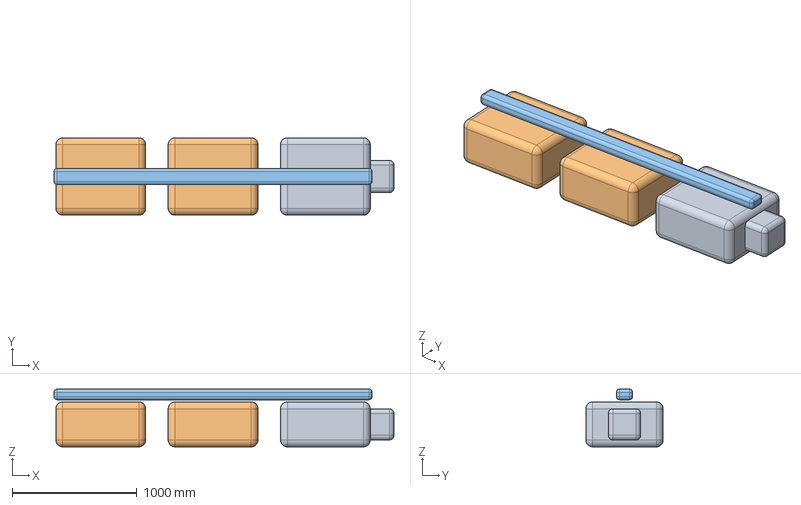
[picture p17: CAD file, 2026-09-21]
cove-s/cad/exports/parts/battery.step
2725.0 x 620.0 x 462.5 mm

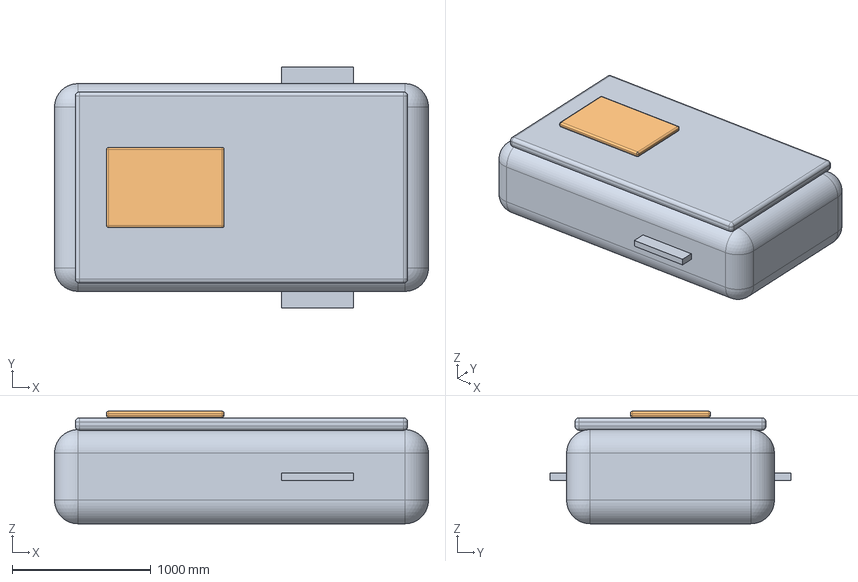
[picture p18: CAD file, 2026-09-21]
cove-s/cad/exports/parts/deckhouse.step
2700.0 x 1740.0 x 812.5 mm

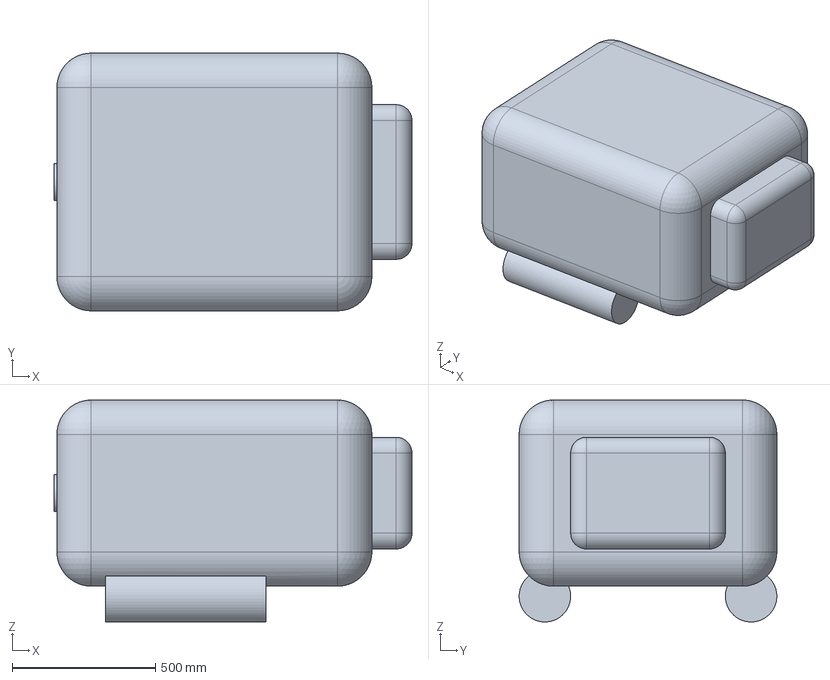
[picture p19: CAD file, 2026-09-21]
cove-s/cad/exports/parts/pto.step
1250.0 x 900.0 x 775.0 mm

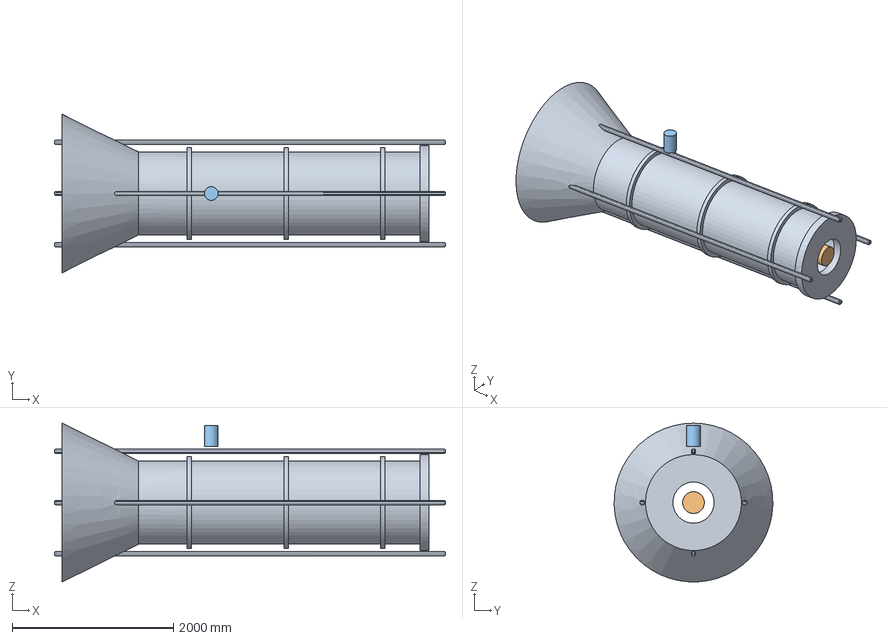
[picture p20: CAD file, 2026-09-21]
cove-s/cad/exports/parts/dock.step
4850.0 x 1969.1 x 1968.1 mm

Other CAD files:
cove-s/cad/exports/parts/surface_hull.step
cove-s/cad/exports/parts/auv.step
cove-s/cad/exports/cove-s-compact-assembly.stl
cove-s/cad/exports/parts/auv.stl
cove-s/cad/exports/parts/battery.stl
cove-s/cad/exports/parts/deckhouse.stl
cove-s/cad/exports/parts/dock.stl
cove-s/cad/exports/parts/electronics.stl
cove-s/cad/exports/parts/foils.stl
cove-s/cad/exports/parts/mast.stl
cove-s/cad/exports/parts/pto.stl
cove-s/cad/exports/parts/reaction_body.stl
cove-s/cad/exports/parts/surface_hull.stl
cove-s/cad/exports/parts/thruster.stl

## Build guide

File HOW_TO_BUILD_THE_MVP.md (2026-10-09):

# How to build the Cove MVP: 14-day home prototype sprint

**Deadline:** end of day 14. **Team:** three people. **Assumed effort:** 15–20 hours per person per week (90–120 team hours total). **Resources:** a small FDM 3D printer, hand tools, a dry work area and water for a supervised test. **Budget:** approximately **$500–1,500 USD** for the sprint, excluding existing tools, labor, an AUV and any pool rental. This is a planning allowance, not a supplier quote.

## What will exist on day 14

A table-sized physical demonstrator with two visible subsystems:

1. **Wave-power rig:** a 0.4–0.6 m surface float, an adjustable submerged reaction plate, a line-driven spool and spring-return power takeoff (PTO), a small DC motor used as generator, and a dry electrical load. It produces logged voltage, current, power, stroke and (if the sensor is ready) line force during repeated motion.
2. **Docking mockup:** a modular 3D-printed funnel on the submerged body and a 0.2–0.3 m passive vehicle shape. The team guides the vehicle into the dock and logs successes and jams. No motorized AUV or wet charging interface is required for this sprint.

The demo claim is **“measured wave-to-electric output plus guided dock capture.”** Charging a real AUV, continuous operation, autonomous navigation, wave propulsion, and the concept's 2 kW output are later milestones. A resistor or LED demonstration does not establish that the platform can charge an AUV. Keep the measured output in watts and watt-hours, however small.

## The fastest physical design

```
   small sealed float (plastic container + foam)      dry electronics on shore
             │                                         V/I logger → resistor
    spring → spool → brushed DC motor ───────────────────────────┘
             │       3D-printed guide + hard stops
             │ adjustable braided line (about 0.3–0.7 m)
      ┌──────┴────────┐
      │ reaction plate │— segmented 3D-printed funnel
      └───────────────┘      ← guided passive vehicle
```

Use a **brushed permanent-magnet DC motor**, which is simple to characterize as a generator. The spring keeps tension on the line for the return stroke. A bridge rectifier makes electrical polarity consistent in both directions if the spool reverses. Begin with a resistor load; add storage only after the generator's real voltage/current range is measured. The float and lower plate are replaceable so the team can test geometry changes. This small arrangement is **not a scale copy** of the [8 m concept CAD](ARCHITECTURE_AND_SCALING.md#concept-cad-and-its-limits).

The printer is most valuable for the motor bracket, spool, fairlead/line guide, travel-stop housings, segmented dock funnel, sensor mounts and passive vehicle shell. Print these as small PETG modules, with bolt holes and spare copies of loaded parts. Use a bought sealed container/foam for buoyancy and a dry box or rated enclosure for electronics. Printed shells may admit water through layer bonds, as [Blue Robotics notes](https://bluerobotics.com/learn/making-an-m200-powered-brush/); do not rely on a print as a battery or pressure housing. Keep the load path backed by metal fasteners and a tether, and inspect printed parts after every run.

**Print queue:** first print a shaft-fit test piece, a small spool (about 40–60 mm outside diameter), line guide and motor mount. After measuring the passive vehicle, print a 200–300 mm long mock body (roughly 40–60 mm diameter) and a funnel with an entry roughly twice its diameter. Split every long part into sections that fit the printer and bolt them to a simple backing plate. These are starting dimensions for an adjustable mockup; fit them to the actual motor shaft, available water depth and printer volume before printing. Aim for 4–5 walls and about 0.2 mm layers in PETG; [Blue Robotics documents similar settings for marine prototype parts](https://bluerobotics.com/learn/making-an-m200-powered-brush/). Make a spare spool and guide while the printer is free.

## Shopping list: buy or borrow on day 1

Prices below are **budget allowances** for local or quickly delivered parts. Inventory and exact motor characteristics must be checked before purchase. Buy two generator candidates or a spare because the schedule has no room for a week-long replacement. A small printer can make the custom parts; do not wait for the full CAD to be converted to printable files.

| Item | Quantity / choice | Allowance |
|---|---|---:|
| Float and submerged plate | One sealed 15–30 L plastic container or foam float; one HDPE cutting board or similar plate; ballast and stainless/nylon fasteners | $60–150 |
| PTO | Two candidate brushed DC motors (roughly 12–24 V nominal), small shaft coupler or pulley, two bearings, spool, return spring, line, hard stops and guard | $90–250 |
| 3D printing | About 1 kg PETG (or existing stock), spare nozzle, bolts/inserts; split large funnel into printable segments | $25–80 |
| Electrical | Bridge rectifier, 2–3 resistor loads with power ratings above measured dissipation, fuse, wire, terminal blocks, dry box and switch | $60–160 |
| Measurement | Multimeter, microcontroller/logger or USB meter, voltage/current sensor, ruler or video scale; optional load cell and amplifier | $90–250 |
| Dock and retrieval | Passive vehicle ballast/foam, soft bumper, guide line, retrieval tether, clamps and spare fasteners | $45–110 |
| Test setup | Tub/basin or pool access, manual wave paddle, towels, cleanup materials, transport | $35–150 |
| **Subtotal** |  | **$405–1,150** |
| **25% contingency** |  | **$101–288** |
| **Sprint total** | Rounded | **$500–1,500** |

No LiFePO4 battery is needed for the minimum demonstration. If time and measured voltage permit a charging experiment, use a matched commercial charger and protected small battery **in a dry enclosure**. Do not infer a charger's suitability from a motor's nominal voltage. A [12 V 20 Ah protected battery currently lists at $89.99](https://www.renogy.com/collections/20-70ah-batteries/products/12v-20ah-trolling-motor-lithium-iron-phosphate-battery), but it and a proper charging circuit are outside the base budget. A small [rated watertight enclosure starts at $61](https://bluerobotics.com/store/watertight-enclosures/wte-vp/) if submerged electronics become necessary; the base rig keeps electrics dry and above water.

## Daily schedule and owners

Assign one **mechanical lead (M)**, one **electrical lead (E)** and one **measurement/test lead (T)**. Everyone joins the water tests and end-of-day review. Parallel tasks in a row can happen on the same day.

| Day | M: make/assemble | E: power and sensors | T: evidence and tests | End-of-day deliverable |
|---:|---|---|---|---|
| 1 | Choose float, plate, line path and printer envelope | Select two motors, load and meter; order/buy locally | Confirm test-water access and video/log format | Parts in hand or firm pickup plan; test site booked |
| 2 | Model and print spool, motor mount and guide | Wire motor to meter and first resistor | Define stroke/speed/load settings; measure baseline meter noise | First spun-by-hand voltage/current reading |
| 3 | Assemble spring return and hard stops | Add rectifier and 2–3 loads | Record bench strokes on video with ruler in frame | PTO moves freely through safe travel |
| 4 | Strengthen mounts and add guard | Add voltage/current logger | Calibrate readings against multimeter | Logged bench power trace |
| 5 | Build float and adjustable plate | Protect connections in dry box | Weigh parts; check estimated displacement/trim | Complete dry-assembled rig |
| 6 | Bench cycle at several strokes; repair jams | Verify fuses and load temperatures | Plot energy per cycle and note uncertainty | **Gate A:** repeatable measured output; choose motor/load |
| 7 | Float and plate trim in still water | Keep generator disconnected for first immersion | Film relative motion and inspect for leaks | Stable, retrievable rig |
| 8 | Tune depth and spring tension | Connect protected dry-side load | Run first controlled-motion water test | Raw water-test power, stroke and video |
| 9 | Change one geometry variable if needed | Verify instrumentation and wiring after water exposure | Repeat still water and 2–3 motion conditions | **Gate B:** motion-to-electric result with baseline |
| 10 | Print segmented dock funnel and passive vehicle | Add optional simple dock contact indicator (no power transfer) | Plan repeatable entry paths | Dock fits and vehicle clears in air |
| 11 | Mount funnel and guides | Secure dry-side instrumentation | Ten guided entries in still water | Capture and jam log |
| 12 | Adjust funnel/ballast | Verify electrical data is still repeatable | Ten guided entries with controlled motion | **Gate C:** capture rate and failure video |
| 13 | Repair one failure; freeze configuration | Re-run electrical checks | Repeat best and worst conditions; organize raw files | Final dataset and 90-second continuous demo video |
| 14 | Inspect wear and disassemble/repack | Record final bill of materials | Write one-page results and next decision | Physical prototype, data, video, cost and revision list |

**Day-6 fallback:** if the chosen motor/PTO does not produce repeatable measured output, use the spare motor and a simpler hand-driven test linkage. Keep the day-14 deliverable as a measured generator bench rig plus the waterborne two-body/dock mockup. Label any hand-driven result as hand-driven. Do not present it as harvested wave energy.

**Water access fallback:** a bathtub can prove buoyancy, relative motion and dock clearance; its short waves and shallow depth cannot establish offshore power performance. For a wave-to-electric test, seek an outdoor pool, sheltered basin or other approved space with enough length and depth for repeatable motion. Keep large water tanks on ground-supported surfaces; water is heavy. If no such site is available by day 1, make day 14 a bench-plus-bathtub demonstrator and state that limitation on the results sheet.

## How to measure success

For every run save: date, revision, water depth, wave/imposed-motion method, plate depth, line length, float/plate mass, spring and load setting, voltage/current time series (target at least 20 samples/second), video, and any jam/leak. Electrical energy delivered to the resistor is the sum of `V × I × Δt`; report the integration interval. If claiming PTO efficiency, also measure force and relative velocity and state instrument error. A battery-powered LED or logger can be an output indicator, but its energy must be accounted for separately.

| Gate | Pass for this sprint | Decision if missed |
|---|---|---|
| A: bench PTO | Two or more repeat runs at each of three imposed stroke speeds give positive electrical energy above meter noise, with no jam or overtravel | Simplify linkage, change gearing/load or use backup motor |
| B: water power | Rig is retrievable and dry; controlled motion gives electrical energy above still-water baseline and measurement uncertainty; log stroke and peak line load if instrumented | Change plate depth, float/plate area or PTO resistance; record result even if no surplus |
| C: dock geometry | At least 8 of 10 **guided** still-water entries succeed without damage; repeat 10 in motion and report actual count | Widen entry, change vehicle buoyancy/guide path; do not claim autonomous docking |
| D: handoff | One-page data summary, raw logs, continuous video, bill of materials and open issues exist on day 14 | Record which subsystem needs the next prototype cycle |

These gates establish a demonstrator, not power output at scale or offshore reliability. The full-size model currently contains unvalidated motion and load assumptions; see the [architecture and scaling guide](ARCHITECTURE_AND_SCALING.md#validation-roadmap). The [IEC early-stage wave-converter guidance](https://tethys-engineering.pnnl.gov/publications/iec-technical-specification-62600-1032024-part-103-guidelines-early-stage-development) calls for measured PTO, motion, load, power and sea-trial evidence as development advances.

## Test-day boundaries

Use low-voltage, fused circuitry and keep mains equipment, batteries and electrical connections dry and accessible. Guard the spring, spool and pinch points; establish a retrieval line before releasing the rig. Never energize exposed underwater charging contacts. Inspect printed load-path parts, lines and stops before each run. Get permission for the water site and keep the prototype supervised. These choices preserve the 14-day schedule by avoiding failures that would consume the entire sprint.

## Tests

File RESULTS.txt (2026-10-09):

Simulation results

Generated by `node run.mjs`. Screening-model outputs, not measurements. Defaults and limits are summarized in ARCHITECTURE_AND_SCALING.md unless a column says otherwise.

## 1. Full product (float → water column → jet → leaf)

Defaults: tube 2 m × 35 mm, nozzle 15 mm, float 0.6 m, hull 40 kg, leaf 150 mm, load 5 MΩ. Net = AC × 0.6 × dock 0.9.

| H (m) | T (s) | AC µW | net µW | peak jet m/s | peak bend mm | strain µε | years per 1 kWh |
|---|---|---|---|---|---|---|---|
| 0.05 | 2 | 1.68 | 0.91 | 0.73 | 4.8 | 159 | 125,965 |
| 0.05 | 3 | 0.38 | 0.20 | 0.51 | 2.3 | 78 | 556,984 |
| 0.05 | 4 | 0.01 | 0.00 | 0.19 | 0.3 | 11 | 30,162,263 |
| 0.05 | 6 | 0.00 | 0.00 | 0.04 | 0.0 | 1 | 2,588,354,814 |
| 0.1 | 2 | 15.90 | 8.59 | 1.29 | 14.7 | 487 | 13,285 |
| 0.1 | 3 | 3.01 | 1.62 | 0.87 | 6.6 | 219 | 70,261 |
| 0.1 | 4 | 0.08 | 0.04 | 0.36 | 1.1 | 37 | 2,536,123 |
| 0.1 | 6 | 0.00 | 0.00 | 0.08 | 0.1 | 2 | 451,474,663 |
| 0.2 | 2 | 119.23 | 64.39 | 2.13 | 39.6 | 1313 | suppressed: Leaf bend exceeds the linear-model range. |
| 0.2 | 3 | 20.04 | 10.82 | 1.39 | 16.9 | 561 | suppressed: Leaf bend exceeds the linear-model range. |
| 0.2 | 4 | 0.94 | 0.51 | 0.66 | 3.8 | 125 | 225,749 |
| 0.2 | 6 | 0.00 | 0.00 | 0.15 | 0.2 | 8 | 57,703,824 |
| 0.3 | 2 | 350.16 | 189.09 | 2.78 | 67.0 | 2221 | suppressed: Leaf bend exceeds the linear-model range. |
| 0.3 | 3 | 56.49 | 30.50 | 1.80 | 28.2 | 933 | suppressed: Leaf bend exceeds the linear-model range. |
| 0.3 | 4 | 3.60 | 1.95 | 0.92 | 7.4 | 244 | 58,602 |
| 0.3 | 6 | 0.01 | 0.01 | 0.22 | 0.5 | 16 | 15,257,514 |

### Water-column tuning (H 0.1 m, T 3 s)

| tube length m | column natural period s | AC µW | peak jet m/s | screen |
|---|---|---|---|---|
| 1 | 2.01 | 0.14 | 0.39 | ok |
| 1.5 | 2.46 | 1.07 | 0.66 | ok |
| 2 | 2.84 | 3.01 | 0.87 | ok |
| 2.5 | 3.17 | 4.57 | 0.97 | ok |
| 3 | 3.47 | 5.04 | 0.99 | ok |
| 4 | 4.01 | 4.27 | 0.96 | ok |

## 2. Single strip (defaults)

AC power 3.47 µW · jet input 28.3 mW · conversion 0.0123% · peak bend 8.71 mm · strain 288 µε · natural 5.96 Hz · 54,824 years per 1 kWh.

## 3. Sheet (cell size × cell count)

Per-cell 150 × 20 mm strip, source jet 15 mm at 1 m/s, 6 s pulses.

| cells | shared AC µW | shared jet mW | shared yrs/kWh | indep. AC µW | indep. jet mW | indep. yrs/kWh | sheet cm² |
|---|---|---|---|---|---|---|---|
| 1 | 3.47 | 28.3 | 54,824 | 3.47 | 28.3 | 54,824 | 30 |
| 4 | 0.87 | 28.3 | 219,295 | 13.87 | 113.2 | 13,706 | 120 |
| 10 | 0.35 | 28.3 | 548,237 | 34.68 | 283.0 | 5,482 | 300 |
| 25 | 0.14 | 28.3 | 1,370,592 | 86.70 | 707.5 | 2,193 | 750 |
| 50 | 0.07 | 28.3 | 2,741,185 | 173.40 | 1415.1 | 1,096 | 1500 |
| 100 | 0.03 | 28.3 | 5,482,369 | 346.80 | 2830.2 | 548 | 3000 |
| 200 | 0.02 | 28.3 | 10,964,739 | 693.60 | 5660.4 | 274 | 6000 |

### Cell size sweep (10 cells, independent jets, load 5 MΩ)

| cell length mm | cell width mm | sheet AC µW | strain µε | natural Hz | screen |
|---|---|---|---|---|---|
| 80 | 15 | 5.93 | 208 | 14.69 | ok |
| 80 | 20 | 5.05 | 155 | 16.55 | ok |
| 80 | 40 | 2.58 | 77 | 21.43 | ok |
| 100 | 15 | 12.86 | 259 | 10.32 | ok |
| 100 | 20 | 10.43 | 194 | 11.57 | ok |
| 100 | 40 | 4.64 | 96 | 14.75 | ok |
| 150 | 15 | 47.53 | 387 | 5.38 | ok |
| 150 | 20 | 34.68 | 288 | 5.96 | ok |
| 150 | 40 | 12.26 | 143 | 7.37 | ok |
| 200 | 15 | 110.02 | 514 | 3.35 | suppressed |
| 200 | 20 | 74.49 | 383 | 3.69 | suppressed |
| 200 | 40 | 23.26 | 190 | 4.45 | ok |
| 300 | 15 | 320.98 | 771 | 1.70 | suppressed |
| 300 | 20 | 199.44 | 575 | 1.84 | suppressed |
| 300 | 40 | 55.46 | 286 | 2.15 | suppressed |

## 4. Proposed node (sealed pendulum → generator → battery → dock → AUV)

Defaults: hull 12 m × Ø2.8 m, pendulum 10000 kg on a 1.1 m arm, spring-tuned to the wave period, generator damping auto-matched, drive efficiency 0.8, availability 0.35, node battery 10 kWh, dock 1500 W at 0.9. AUV 4500 Wh arriving at 10%.

| configuration | electrical W | capture width / hull length | pendulum swing ° | kWh/day | session h | charges/day | screen |
|---|---|---|---|---|---|---|---|
| default 12 m / 10 t, H 1 m T 6 s | 994 | 0.028 | 38 | 8.35 | 3.0 | 1.86 | ok |
| default, H 0.5 m | 427 | 0.048 | 29 | 3.59 | 3.0 | 0.80 | ok |
| default, H 1.5 m T 5 s | 2804 | 0.042 | 50 | 23.55 | 3.0 | 5.23 | ok |
| default, H 2 m T 8 s | 628 | 0.003 | 37 | 5.27 | 3.0 | 1.17 | ok |
| default, H 1 m T 10 s | 161 | 0.003 | 27 | 1.35 | 3.0 | 0.30 | ok |
| 10 m / 6 t, H 1 m T 6 s | 487 | 0.017 | 37 | 4.09 | 3.0 | 0.91 | ok |
| 8 m / 3 t, H 1 m T 6 s | 191 | 0.008 | 38 | 1.60 | 3.0 | 0.36 | ok |
| 8 m / 3 t, H 1.5 m T 5 s | 580 | 0.013 | 51 | 4.87 | 3.0 | 1.08 | ok |
| 4.5 m / 0.4 t (earlier design doc), H 1 m T 6 s | 5 | 0.000 | 28 | 0.04 | 3.0 | 0.01 | ok |
| default, gravity pendulum only (no spring) | 136 | 0.004 | 5 | 1.14 | 3.0 | 0.25 | ok |

## 5. Cove S (mobile wave-powered small-AUV service station)

Defaults: 14-day variable offshore scenario, 60 kWh station battery with 20% protected reserve, 2.0 kW WEC, 0.35 m effective capture width, 3.0 kWh AUV arriving at 20%, and 1 visit/day. Built-in sea histories are representative screening scenarios, not measured sites.

| scenario | wave kWh | AUVs charged | deferred | distance km | minimum SOC | ending SOC | result |
|---|---|---|---|---|---|---|---|
| design sea | 193.0 | 14 | 0 | 655 | 70% | 100% | closes |
| variable offshore | 127.4 | 14 | 0 | 548 | 70% | 98% | closes |
| three-day calm spell | 82.8 | 14 | 0 | 388 | 70% | 80% | The WEC feathers during cut-in or survival sea states. |
| storm and survival | 207.1 | 14 | 0 | 545 | 70% | 98% | The WEC feathers during cut-in or survival sea states. |
| variable, 5 kWh AUV | 127.4 | 14 | 0 | 548 | 70% | 92% | closes |
| variable, 2 AUVs/day | 127.4 | 28 | 0 | 548 | 70% | 89% | closes |
| calm, 20 kWh station battery | 82.8 | 14 | 0 | 388 | 29% | 41% | The WEC feathers during cut-in or survival sea states. |

## 6. PVC pipe linear generator (magnet sliding through coils)

Defaults: 1000 mm travel in a 50 mm bore, 40×50 mm NdFeB magnet (0.47 kg), 1×1000 turns of 0.5 mm wire, load auto-matched. "Levitation" = no spring: the end magnets hold the magnet up and set the stiffness.

| H (m) | T (s) | load power | natural period s | stroke mm | peak EMF | years per 1 kWh |
|---|---|---|---|---|---|---|
| 0.5 | 4 | 2.45 nW | 0.25 | 1.97 | 590 µV | 46,527,109 |
| 0.5 | 6 | 0.04 nW | 0.25 | 0.85 | 74 µV | 2,743,814,789 |
| 0.5 | 8 | 2.3e-12 W | 0.25 | 0.48 | 17 µV | 48,980,697,307 |
| 1 | 4 | 41.32 nW | 0.25 | 4.12 | 3 mV | 2,760,817 |
| 1 | 6 | 0.67 nW | 0.25 | 1.74 | 306 µV | 169,757,168 |
| 1 | 8 | 0.04 nW | 0.25 | 0.96 | 70 µV | 3,051,526,419 |
| 2 | 4 | 810.66 nW | 0.25 | 9.07 | 13 mV | 140,722 |
| 2 | 6 | 11.20 nW | 0.25 | 3.62 | 1 mV | 10,189,643 |
| 2 | 8 | 0.61 nW | 0.25 | 1.97 | 293 µV | 188,301,503 |

### Suspension stiffness (H 1 m, T 6 s)

The end magnets must hold the magnet up, so with no spring the suspension is stiff and the magnet rides with the pipe. Softening it toward the 6 s wave means a spring that sags at least g/ω² = 8.95 m under any mass.

| suspension | spring N/m | load power | natural period s | stroke mm | peak EMF | static sag m | screen |
|---|---|---|---|---|---|---|---|
| levitation (magnets only) | — | 0.67 nW | 0.25 | 1.74 | 306 µV | 0.00 | ok |
| 500 N/m | 500.00 | 0.10 nW | 0.19 | 1.03 | 108 µV | 0.01 | ok |
| 50 N/m | 50.00 | 972.90 nW | 0.61 | 10.43 | 11 mV | 0.09 | ok |
| 5 N/m | 5.00 | 1.94 mW | 1.93 | 91.63 | 907 mV | 0.92 | suppressed: A vertical spring this soft sags 0.9 m under |
| tuned to the wave | 0.50 | 11.41 mW | 6.00 | 611.28 | 4.1 V | 9.30 | suppressed: A vertical spring this soft sags 9.3 m under |

### Scaling the pipe (tuned suspension, H 1 m, T 6 s)

The best case this architecture can reach, ignoring that the tuned suspension above is not buildable vertically.

| pipe | magnet kg | load power | natural period s | stroke mm | peak EMF |
|---|---|---|---|---|---|
| 50 mm bore, 1 m, 1 coil | 0.5 | 11.41 mW | 6.00 | 611.28 | 4.1 V |
| 50 mm bore, 1 m, 10 coils | 0.5 | 13.40 mW | 6.00 | 560.32 | 6.9 V |
| 110 mm bore, 2 m, 10 coils | 8.8 | 1.08 W | 6.00 | 1214.84 | 68.3 V |
| 160 mm bore, 4 m, 20 coils | 39.8 | 7.43 W | 6.00 | 2087.46 | 208.3 V |

### The tuning wall

A vertical spring-mass tuned to a wave period sags g/ω² under its own weight, whatever the mass. That is the same length as a pendulum of the same period — which is why the pendulum node reaches wave frequency in a 12 m hull and a straight pipe cannot.

| wave period s | required stiffness / mass 1/s² | static sag m |
|---|---|---|
| 4 | 2.467 | 3.98 |
| 6 | 1.097 | 8.95 |
| 8 | 0.617 | 15.90 |
| 10 | 0.395 | 24.85 |
| 12 | 0.274 | 35.78 |

## 7. Horizontal pipe: sizing for one AUV charge per day

Lying the pipe flat takes gravity off the axis, so the suspension no longer has to hold the magnet up and can be tuned to the wave. The magnet then rests on the bore instead, and sliding friction replaces the sag as the limit. Both the friction force and the wave forcing scale with the magnet mass, so their ratio mu·g/(a·ω²) is a property of the sea state and the bearing alone — no magnet is heavy enough to break loose if it exceeds 1.

| wave | breakaway limit on mu (a·ω²/g) |
|---|---|
| H 0.5 m, T 6 s | 0.028 |
| H 1 m, T 6 s | 0.056 |
| H 1 m, T 4 s | 0.126 |
| H 1.5 m, T 5 s | 0.121 |
| H 2 m, T 4 s | 0.252 |
| H 2 m, T 8 s | 0.063 |

### Friction is the whole design (12 m pipe, H 1 m, T 6 s)

| bore friction mu | friction / wave forcing | load power | friction loss | stroke m | screen |
|---|---|---|---|---|---|
| 0.003 | 0.06 | 671.14 W | 60.00 W | 7.08 | ok |
| 0.01 | 0.19 | 581.33 W | 223.08 W | 8.24 | ok |
| 0.02 | 0.39 | 385.15 W | 448.07 W | 8.34 | ok |
| 0.03 | 0.58 | 149.98 W | 517.42 W | 6.57 | ok |
| 0.05 | 0.97 | 130.88 mW | 2.82 W | 0.03 | suppressed: Sliding friction is 0.97× the wave forci |
| 0.1 | 1.93 | 17.61 mW | 1.07 W | 0.01 | suppressed: Sliding friction is 1.93× the wave forci |

### How big it has to get (horizontal, tuned, mu 0.01, H 1 m / T 6 s)

One 4.5 kWh AUV arriving at 10% needs 482 W of load power at 35% availability. Every dimension scales together; coils fill the pipe and the load is chosen for maximum power among the settings whose stroke still fits the travel.

| bore | pipe m | magnet kg | coils | load power | stroke m | W per kg | charges/day |
|---|---|---|---|---|---|---|---|
| 50 mm | 1.0 | 0 | 16 | 7.95 mW | 0.43 | 0.017 | 0.00 |
| 100 mm | 2.0 | 4 | 16 | 358.79 mW | 1.34 | 0.095 | 0.00 |
| 200 mm | 4.0 | 30 | 16 | 7.01 W | 2.81 | 0.233 | 0.01 |
| 400 mm | 8.0 | 241 | 16 | 118.35 W | 5.57 | 0.491 | 0.25 |
| 500 mm | 10.0 | 471 | 16 | 286.88 W | 6.90 | 0.609 | 0.60 |
| 550 mm | 11.0 | 627 | 16 | 414.14 W | 7.55 | 0.660 | 0.86 |
| 600 mm | 12.0 | 814 | 16 | 581.33 W | 8.24 | 0.714 | 1.21 |
| 650 mm | 13.0 | 1035 | 16 | 798.66 W | 8.92 | 0.771 | 1.66 |

### The sized unit

| quantity | value |
|---|---|
| bore | 600 mm |
| pipe travel length | 12.0 m |
| magnet | 480 × 600 mm NdFeB, 814 kg |
| winding | 16 × 1500 turns of 5 mm wire |
| tuning spring | 890 N/m → 6.00 s natural period |
| stroke | 8.24 m peak to peak in 11.4 m of travel |
| load / coil resistance | 1585 Ω / 44 Ω |
| load power | 581.33 W |
| copper loss | 16.02 W |
| friction loss | 223.08 W |
| peak EMF | 1938 V |
| charges per day | 1.21 |

### The same unit across sea states

| sea state | load power | stroke m | charges/day |
|---|---|---|---|
| 0.5 m / 6 s | 140.83 W | 6.35 | 0.29 |
| 1 m / 6 s | 581.33 W | 8.24 | 1.21 |
| 1.5 m / 5 s | 1564.25 W | 9.04 | 3.24 |
| 2 m / 4 s | 3751.28 W | 9.09 | 7.78 |
| 2 m / 8 s | 534.16 W | 8.49 | 1.11 |
| 1 m / 10 s | 52.04 W | 6.36 | 0.11 |

## Reading these numbers

Every configuration here lands in the microwatt range while the prescribed jets carry tens of milliwatts to watts; conversion is 10⁻⁴ to 10⁻² percent because a 0.17–0.5 Hz pulse bends a 6 Hz strip quasi-statically. Adding cells on a shared source reduces total power (per-cell force ∝ 1/N, power ∝ 1/N², N cells → 1/N). Independent jets scale linearly but the total jet input must come from the wave-to-water stage, which the full-product model shows delivers under a watt of jet power at a 0.1 m wave. Charging a 1 kWh vehicle is 10⁴–10⁶ years in every case.

The pendulum node closes the gap because it puts tonnes, not grams, in motion at wave frequency and takes the energy out with a generator at ~80% instead of a piezo at 0.01%. The size needed is set by the physics of an inertial absorber (power scales with pendulum mass × wave height² ÷ period³): roughly a 10–12 m hull with a 6–10 t spring-tuned pendulum gives one small-survey charge per day in 1 m / 6 s seas; an 8 m hull with 3 t does it at a short-period 1.5 m site. The 4.5 m / 400 kg unit in the earlier design document makes single-digit watts in the same seas and is a sensor-power node, not an AUV charger. The charge session itself (3 h at 1.5 kW) always comes from the node battery; the waves decide how many sessions per day the battery can be refilled for.

The PVC pipe generator removes the piezo conversion penalty — a coil and a magnet are an efficient transducer — and still lands in the nanowatt range as built, for a different reason: the suspension. Repelling end magnets strong enough to hold the magnet up are stiff (0.25 s natural period against a 6 s wave), so the magnet rides with the pipe instead of lagging it, and the relative stroke is under 2 mm. Softening the suspension to wave frequency is not a tuning choice but a geometry problem: a vertical spring-mass at 6 s sags 8.95 m under its own weight regardless of mass, more travel than the pipe has. Even granting the impossible spring, a 4 m pipe with a 40 kg magnet and 20 coils reaches single-digit watts. A pendulum escapes this because its restoring torque comes from gravity itself and a torsion spring adds stiffness without having to carry the weight, which is why the same 8.95 m appears as a hull dimension rather than a spring deflection.

Laid flat the pipe escapes the sag and buys a friction problem instead: the magnet rests on the bore, and it only breaks loose if the bearing keeps mu below a·ω²/g — 0.056 in 1 m / 6 s seas, which rules out a magnet sliding on plastic and demands rollers or a radial bearing. Granted mu = 0.01, one AUV charge per day needs a 12 m pipe of 600 mm bore holding an 814 kg NdFeB magnet that strokes 8.2 m, for 581 W. That is the same 12 m length as the pendulum node for a similar duty, but the node makes its moving mass out of whatever is heavy and cheap, while here the moving mass has to be the magnet itself — roughly fifty thousand dollars of neodymium, plus an 8 m sliding seal, against a 10 t block of steel or concrete on a shaft.

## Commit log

2026-09-18 feat: add PVC pipe linear generator model
    A sealed pipe heaves with the wave while a magnet slides in the bore past
    coils wound outside it. Removes the piezo conversion penalty but lands in
    the nanowatt range as built: end magnets strong enough to levitate the
    magnet give a 0.25 s natural period against a 6 s wave, so the magnet
    rides with the pipe and the stroke stays under 2 mm.
    The suspension screen is the result. A vertical spring-mass tuned to the
    wave period sags g/w^2 under its own weight -- 8.95 m at 6 s, independent
    of mass -- which is more travel than the pipe has. That is the same length
    as a pendulum of the same period, which is why the pendulum node reaches
    wave frequency insid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
2026-09-18 feat: horizontal pipe orientation, friction limit, and sizing for one AUV/day
    Adds tilt and a bore friction coefficient to the pipe model. Because the
    deep-water orbit is circular, the axial forcing amplitude is the same at
    any tilt, so tilt only trades one limit for another: axial gravity falls
    as cos(tilt), which removes the static-sag wall and makes the suspension
    tunable, while the magnet's weight moves onto the bore as Coulomb friction
    mu*m*g*sin(tilt).
    Friction and forcing both scale with the magnet mass, so breakaway needs
    mu*g*sin(tilt)/(a*w^2) < 1 -- a property of the sea state and the bearing
    alone. No magnet is heavy enough to break its own friction loose. In
    1 m / 6 s seas that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
2026-09-18 Organize repo into per-simulation folders
    Group each screening model's source, template, built HTML page, and
    check script into its own folder (strip/, sheet/, product/, tube/,
    node/), and update build.mjs, run.mjs, cross-folder imports, and docs
    to match.
2026-09-21 cove-s prototype
    [auv.step, auv.stl, battery.step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]
2026-10-09 Document Good Bull pitch and display model
    [Cove_end_cap_print_twice.stl, Cove_shell_section_print_twice.stl]
